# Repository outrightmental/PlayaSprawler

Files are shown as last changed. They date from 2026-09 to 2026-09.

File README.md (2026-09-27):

# Playa Sprawler

**Open-source personal mobility optimized for accessibility and maintainability.**
A camp chair on four identical, hot-swappable, self-powered wheel modules — packed into one piece
of Burner Express luggage, rated to the rider's mass down to every tube, joint and cord, and
repaired by a community fleet in under a minute.

Site: **https://playasprawler.outright.io** · structured after [BoardingFlow](https://boardingflow.outright.io/).

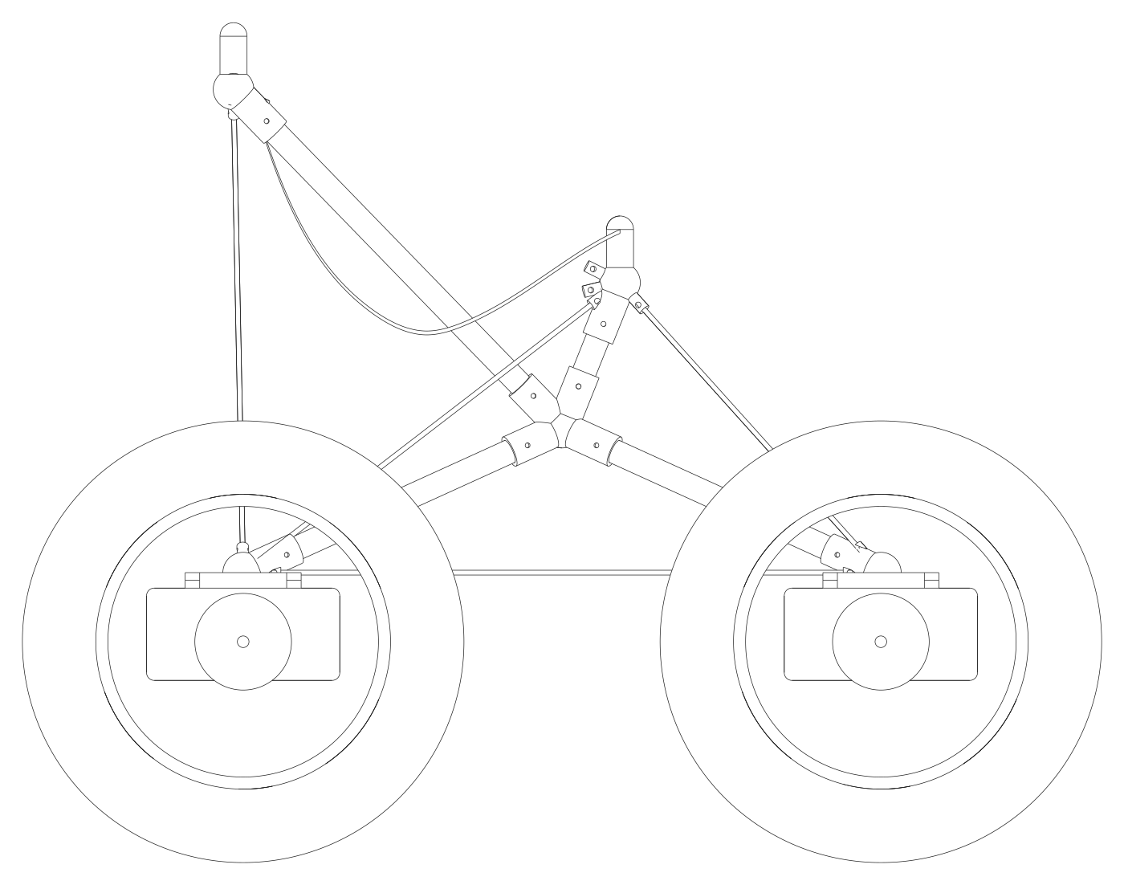
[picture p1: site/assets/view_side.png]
Side view, generated from the parameter file


## The idea in five lines

1. **Four identical wheel modules** (motor + gearbox + brake + battery + Ethernet node in one brick) dock anywhere on the frame; the dock tells the module which corner it is.
2. **Two identical control modules** (left tread, right tread) — lever, pedal, joystick, sip-puff: any input form publishes the same message.
3. **Ethernet only** for signals (M12 D-coded, UDP multicast pub/sub, no master); a separate SELV power bus. Traction current never crosses a dock.
4. **A rating code in the DNA**: every load-path part is analysed, proof-tested and marked PS-100 / PS-125 / PS-150; the vehicle's rating is the weakest part, enforced on the label and in firmware.
5. **One bag** — 62 linear inches, 50 lb — on the Burner Express bus. This constraint designed the vehicle.

## Repository

```
analysis/    ps_params.py (single source of truth) + truss, stability, energy, flotation, axle, packing → results/
cad/         CadQuery generator: joiners grown from the frame geometry, wheel-module carrier, assembly → exports/ (STEP, STL, SVG)
firmware/    PS-Bus reference simulator (deterministic + real UDP multicast) and message schemas
docs/        methodology, requirements, architecture, rating code, module specs, tests, fleet ops, regulatory, caveats, ADRs, sources
seat/        seat flat pattern (generated)
site/        the single-page site (src/ template + app.js → index.html via scripts/build_site.py)
scripts/     build_site.py, check_ratings.py (CI gate)
.github/     deploy.yml (main → S3 + CloudFront), pr.yml (analysis, CAD, simulator, site preview)
```

## Run it

```bash
pip install -r requirements.txt
cd analysis && python run_all.py            # results/results.md + results.json for all rating classes
cd ../cad && python ps_cad.py               # exports/*.step, *.stl, view_*.svg
python ../firmware/sim/psbus_sim.py --check # scripted hot-swap scenario with assertions
python ../scripts/check_ratings.py          # the rating gate CI runs
python ../scripts/build_site.py             # site/index.html
```

Change a number in `analysis/ps_params.py`; everything downstream regenerates. Never edit a
number in a doc or on the site by hand.

## Headline numbers (PS-125, from `analysis/results/results.md`)

| | |
|---|---|
| Bag | 660 × 450 × 450 mm (61.4 in), **22.49 kg of 22.68 kg** — margin 0.19 kg |
| Wheel module | 16 × 3.0 tubeless on a mini geared hub motor, 7s1p 85.7 Wh, 4.35 kg, 135 mm wide |
| Frame | 25 × 22 CF tube (0.74 kg), 10 printed joiners, 5 mm Dyneema cords, structural canvas seat |
| Worst safety factors, 2.5 g | tube 11.1 · cord 3.7 · seat edge 3.7 · axle 2.1 (assumed steel) |
| Stability | tip at 0.49 g lateral; limiter at 0.25 g; 2.0 m minimum radius at 8 km/h |
| Range | 23 km hard playa · 8 km soft playa · 2.5 km dry loose sand |
| Fail-safe | wheel stops 200 ms after the last valid command, 300 ms ramp |

## Read this first

`docs/13-caveats.md`. There is no prototype yet; the mass margin is 0.8 %; the axle steel is
assumed; the vehicle is only legal in Black Rock City as an Accessibility Vehicle for a rider with
a documented need.

## CI and deployment

Two workflows, mirroring the Outright Mental static-site pattern:

* **`pr.yml`** — on every pull request: analysis, rating gate, CAD export, simulator self-check,
  site build, and a `site-preview` artifact.
* **`deploy.yml`** — on push to `main`: the same build, then `aws s3 sync` to the
  `playasprawler.outright.io` bucket (immutable cache headers on `assets/`, `must-revalidate` on
  `index.html`) and a CloudFront invalidation.

One-time setup for the deploy target:

1. S3 bucket `playasprawler.outright.io` (private, served through CloudFront with an origin access control), default root object `index.html`.
2. CloudFront distribution with an ACM certificate for `playasprawler.outright.io` (us-east-1).
3. Route 53 / DNS: `playasprawler.outright.io` → the distribution.
4. Repository secrets: `AWS_ACCESS_KEY_ID`, `AWS_SECRET_ACCESS_KEY` (an IAM user limited to that bucket and `cloudfront:CreateInvalidation` on that distribution), `AWS_CLOUDFRONT_DISTRIBUTION_ID`.

## License

Hardware CERN-OHL-S-2.0 · software Apache-2.0 · documentation CC-BY-SA-4.0. See `LICENSE.md`.

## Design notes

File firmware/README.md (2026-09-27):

# Firmware

* `sim/psbus_sim.py` — the behavioural reference for every node type. `python sim/psbus_sim.py --check`
  runs the scripted hot-swap scenario on a deterministic in-process bus and asserts the timing rules;
  `--transport udp` runs a single node on real multicast for bench work.
* `schemas/psbus-message.schema.json` — JSON Schema for every PS-Bus v1 message.

Production targets (not yet written): an MCU with a hardware 100BASE-TX PHY per node, FOC motor
controller in the wheel module, zenoh-pico or a hand-rolled UDP loop. The simulator's node classes
are the spec those ports must match (`docs/06`).

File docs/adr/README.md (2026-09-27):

# Architecture decision records

* [ADR-001](ADR-001-per-module-battery.md) — The wheel module is the battery
* [ADR-002](ADR-002-skid-steer.md) — Skid steer, no steering mechanism
* [ADR-003](ADR-003-ethernet-m12-pubsub.md) — Ethernet-only signalling, UDP multicast, geographic addressing
* [ADR-004](ADR-004-16x3-tire.md) — 16 × 3.0 folding tubeless tire, packed deflated
* [ADR-005](ADR-005-cords-not-tubes.md) — Dyneema cords close the truss; the seat is structural
* [ADR-006](ADR-006-protocol-json-udp.md) — JSON over UDP multicast for v1, CBOR/zenoh reserved

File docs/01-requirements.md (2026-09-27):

# 01 — Requirements

Verification: **A** analysis · **T** test · **I** inspection · **D** demonstration. Numbers in
parentheses are the current design values from `analysis/results/results.md`.

## 1. Transport — one bag on the Burner Express

| ID | Requirement | V |
|---|---|---|
| REQ-010 | The complete vehicle, disassembled, fits in one soft bag ≤ 62 linear inches (chosen 660 × 450 × 450 mm = 61.4 in). | I |
| REQ-011 | Bag mass including the bag ≤ 50 lb / 22.68 kg (budget 22.49 kg, +0.19 kg margin). | T |
| REQ-012 | Packing and unpacking each take ≤ 15 min by one person without tools. | D |
| REQ-013 | Lithium cells travel inside the wheel modules; packs are ≤ 100 Wh each (85.7 Wh) and carry a state-of-charge indicator. | I |

## 2. Wheel module

| ID | Requirement | V |
|---|---|---|
| REQ-020 | All four wheel modules are identical and interchangeable in any dock without adjustment or configuration. | D |
| REQ-021 | A module can be exchanged in ≤ 60 s with the rider seated (one latch, no tools). | T |
| REQ-022 | Each module contains motor, gearbox, brake, controller, battery and network node; traction current never crosses the dock. | I |
| REQ-023 | Continuous drawbar per module ≥ 60 N at 8 km/h (soft playa 10 % grade needs 230 N total). | A/T |
| REQ-024 | Module mass ≤ 4.35 kg. | T |

## 3. Control module

| ID | Requirement | V |
|---|---|---|
| REQ-030 | Two control modules, one per side (CL, CR). Each publishes one normalised tread command `v ∈ [−1, +1]` at 50 Hz. | D |
| REQ-031 | Any input form (lever, pedal, joystick axis, sip-puff…) is a valid control module; the vehicle cannot tell them apart. | D |
| REQ-032 | A control module is hot-swappable; loss of one side stops that side within 200 ms + 300 ms ramp. | T |
| REQ-033 | Inputs have a mechanical or firmware dead-band ≥ 5 % around zero and return to zero when released. | T |

## 4. Network and power

| ID | Requirement | V |
|---|---|---|
| REQ-040 | Signals travel only over 100BASE-TX Ethernet on M12 D-coded connectors; no other signal wiring exists. | I |
| REQ-041 | Every node is a UDP-multicast pub/sub peer; there is no master for control messages. | D |
| REQ-042 | A node learns its role from the dock ID pin (geographic addressing); no per-node configuration. | D |
| REQ-043 | Primary power is a separate SELV bus (21–29.4 V) on M12 A-coded connectors, per-port limited to 5 A. | I/T |
| REQ-044 | Wheel nodes stop if no valid command arrives within 200 ms; all nodes stop on `veh/estop`. | T |
| REQ-045 | Losing the bus node (switch) is a safe state: all wheels stop. | T |

## 5. Structure and rating

| ID | Requirement | V |
|---|---|---|
| REQ-050 | Every vehicle carries a rating class PS-100 / PS-125 / PS-150 (payload kg). | I |
| REQ-051 | Every load-path part is rated and marked; vehicle rating = min(part ratings). | I |
| REQ-052 | Load cases LC1 (1.0 g static), LC2 (2.5 g vertical), LC3 (1.0 g + 0.6 g lateral), LC5 (0.5 W backrest) with SF tube 2.0, cord 3.0, fabric 3.0, print 1.5 on knocked-down allowables. | A |
| REQ-053 | Every load-path part passes a 1.5 × static proof load before marking. | T |
| REQ-054 | Static seated deflection at the rear tips ≤ 20 mm at class payload (15.5 mm at PS-125). | A/T |
| REQ-055 | No mechanism: the frame is kinematically stable in every load case with the seat installed. | A |
| REQ-056 | Printed parts use CF-filled nylon or PET with 100 % infill in load regions; datasheet strength knocked down by 0.5. | I |

## 6. Mobility and terrain

| ID | Requirement | V |
|---|---|---|
| REQ-060 | Speed cap 8 km/h (BRC 5 mph) in `run`; 2 km/h in `crawl`. | T |
| REQ-061 | Firmware turn-rate limiter `|ω|·|v| ≤ 0.25 g` (tip threshold 0.49 g). | A/T |
| REQ-062 | Range ≥ 15 km on hard playa at class payload (23 km predicted). | A/T |
| REQ-063 | Ground pressure ≤ 40 kPa at class payload for dry sand; 20 × 4.0 variant ≤ 30 kPa. | A/T |

## 7. Fleet

| ID | Requirement | V |
|---|---|---|
| REQ-070 | A fleet charger accepts any wheel module through the standard dock connector. | D |
| REQ-071 | Every part carries a QR label: class · part · batch · maker · proof date. | I |
| REQ-072 | The supervisor logs hello/rating records so a fleet steward can audit what was on which vehicle. | D |

## 8. Regulatory

| ID | Requirement | V |
|---|---|---|
| REQ-080 | The vehicle is designed and documented as a powered mobility device (ISO 7176 / EN 12184 reference); it is not a scooter or golf cart. | I |
| REQ-081 | Lights: white front, red rear, side marker at night per BRC vehicle policy. | I |
| REQ-082 | Riders check current BRC Accessibility Vehicle and GGNRA Ocean Beach rules before use (see `docs/12`). | I |

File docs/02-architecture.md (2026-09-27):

# 02 — Architecture

The sketch that started the project drew a box (battery · motor · gearbox · brake · electronics,
"4× redundant unit"), a camp-chair frame, two foot controls, a signal bus and a network
`W W W W — B — C C — I 1..n — L 1..n`. The architecture keeps exactly that shape.

```
            ┌────────────── PS-Bus (100BASE-TX, UDP multicast) ──────────────┐
            │                                                                 │
   W(FL) ───┤   W(FR) ───┤   W(RL) ───┤   W(RR) ───┤   C(CL) ──┤  C(CR) ──┤   I 1..n  L 1..n
     │            │           │            │            │           │          │       │
   ══╪════════════╪═══════════╪════════════╪════════════╪═══════════╪══════════╪═══════╪══  power bus (SELV 21–29.4 V)
                                        ┌───┴───┐
                                        │   B   │  unmanaged switch + supervisor + charge input
                                        └───────┘
```

## Node types

| Node | Count | Role | Publishes | Subscribes |
|---|---|---|---|---|
| **W** wheel module | 4 | traction, braking, battery, node | `wheel/<pos>/status` 10 Hz, `node/<serial>/hello` 1 Hz | `ctrl/tread/<side>`, `veh/mode`, `veh/estop` |
| **C** control module | 2 | rider input → normalised tread command | `ctrl/tread/<side>` 50 Hz, hello | `veh/mode` (for haptics/LED) |
| **B** bus node | 1 | 8-port unmanaged switch, supervisor MCU, power distribution, charge input, e-stop button | `veh/mode`, `veh/estop`, `veh/log` | everything |
| **I** input | 0..n | horn, lights switch, phone app, spare inputs | `input/<n>/event` | — |
| **L** load | 0..n | lights, sound, whatever the seat decorator wants | — | `light/<n>/cmd`, `veh/mode` |

Every port on the vehicle is the same port: **DATA** (M12 D-coded, Ethernet) + **POWER/ID**
(M12 A-coded, 4 pins: bus +, bus −, ID, spare). The ID pin is a resistor to bus − inside the dock;
its value tells the node which dock it is in: FL, FR, RL, RR, CL, CR, AUX1..n.

## Skid steer

There is no steering mechanism. The left tread command drives both left wheels, the right tread
command both right wheels. Turning = differential speed. This is what makes the four modules
identical: no module knows anything about steering geometry, only which side it is on
(and left-side nodes invert their motor sign).

## Power

Each wheel module carries a 7s1p pack (25.2 V nominal). The vehicle power bus runs at pack
voltage. Each module connects to the bus through an ideal-diode discharge path (so the highest
pack feeds the bus, never back-feeds another pack) and a current-limited charge path (≤ 3–5 A).
Consequences:

* one charger on the B node charges and balances all four packs;
* control modules, lights and the switch buck-convert from the bus; no PoE hardware needed;
* traction current stays inside the module — the dock connector only carries ≤ 5 A.

## Safety chain (what stops the wheels)

1. Rider releases input → command goes to 0 → wheels ramp down at 0.30 g.
2. Any control message stops arriving → wheel stops itself within 200 ms + 300 ms ramp.
3. Supervisor sees a missing wheel (status silent > 250 ms) → `veh/mode = stop`.
4. Any part reports a rating below the rider class → `veh/mode = crawl` (2 km/h).
5. E-stop button on B, or any node publishing `veh/estop` → all stop.
6. B node dies → no switch → no messages → every wheel stops by rule 2.

## Structure

The frame is a tensegrity-flavoured camp chair: two printed hubs joined by the seat rail, four
carbon legs down to the four docks, two carbon poles up to the backrest tips, two short posts to
the front seat tips, and Dyneema cords (side, rear, X-braces, forestays, aftstays, crossed
backstays) that close the truss. The canvas seat is a structural member: its side straps and edge
webbing carry real load, which is why it is rated like everything else (`docs/08`).

## Where things live

```
analysis/   parameters + all calculations → results/
cad/        CadQuery generator → exports/ (STEP, STL, SVG)
firmware/   PS-Bus reference simulator + message schemas
docs/       this folder, ADRs, sources
seat/       seat pattern
site/       playasprawler.outright.io
```

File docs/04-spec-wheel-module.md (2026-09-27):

# 04 — Wheel module spec (interface v1)

**One part number. Four per vehicle. Any dock.**

## Interface (frozen)

| Item | Spec |
|---|---|
| Mechanical | fore/aft-symmetric T-rail on top of the carrier (stem 12 × 8 mm, head 24 × 8 mm, 120 mm long) sliding into the dock shoe; one Ø8 mm spring drop-pin captures it. Rail top = dock plane 300 mm above ground. |
| Load path | rail → shoe → printed dock joiner → legs/cords. Rated per class like every other load-path part. |
| Data | M12 D-coded female, 100BASE-TX. |
| Power/ID | M12 A-coded 4-pin female: 1 bus +, 2 bus −, 3 ID (reads dock resistor), 4 spare. Port fuse 5 A. |
| Module envelope | 135 mm wide (45 carrier + 5 gap + 76 tire + 9 nut), 457 mm OD inflated, 400 mm deflated. |
| Mass | ≤ 4.35 kg. |
| Ingress | IP54 module, IP65 connectors, mated or capped. |

## Internals (free to improve within the envelope)

| Sub-part | Baseline |
|---|---|
| Wheel | 16 × 3.0 (ISO 76-305) folding-bead tubeless tire on a 20-hole rim laced to the hub motor; sealant. |
| Motor | mini geared hub motor, 250 W nominal / 500 W peak, 20 N·m rated / 35 N·m peak, no-clutch (regen-capable) variant preferred so regen braking and hold-on-slope work. |
| Brake | regen + the gearbox's holding torque for service; a friction parking brake is not required at 8 km/h (T-8 verifies the 1.5 m stop on 10 % grade). |
| Battery | 7s1p 18650 3.4 Ah (25.2 V, 85.7 Wh, 0.41 kg) with BMS, on the inboard carrier. Fuel gauge LED. |
| Controller | FOC controller with hall + current sensing; speed control with torque limit; limits from `veh/mode`. |
| Node | small MCU with 100BASE-TX PHY (or an ESP32-class MCU + external PHY); runs the PS-Bus reference behaviour. |
| Carrier | printed "brick" 45 mm thick inboard of the wheel; aluminium torque plates clamp the axle flats; single-sided axle clamp (see caveat). |

## Behaviour

* On power-up: read ID pin → role (FL/FR/RL/RR) → side (left inverts motor sign) → subscribe.
* `ctrl/tread/<side>` at 50 Hz: `v ∈ [−1, 1]` → target speed `v × cap(mode)`; accel ≤ 0.25 g, decel ≤ 0.30 g.
* No valid command for 200 ms → ramp to zero in 300 ms and hold.
* Publish `wheel/<pos>/status` at 10 Hz (speed, SoC, temperature, fault, stop reason) and `hello` at 1 Hz (serial, rating, firmware).
* Thermal derate above 80 °C winding; cut at 95 °C.

## Analysis summary (PS-125)

| Quantity | Value |
|---|---|
| Per-wheel torque, hard playa flat / soft 10 % | 1.6 / 13.2 N·m |
| Per-wheel torque, dry loose sand 10 % | 24.7 N·m → above rated: derate speed |
| Axle bending + torque, LC2 | 368 MPa von Mises, SF 2.1 on assumed 785 MPa yield |
| Ground pressure 16 × 3.0 at 40 kPa | 90 cm² patch, 16 mm deflection — OK |

## Variants

* **PS-Lite**: 16 × 2.4 tire, −0.2 kg per module (mass margin ~5 %), poorer sand flotation.
* **PS-Sand**: 20 × 4.0 tire, 30 kPa at 30 psi-equivalent; does not fit the one-bag pack (two bags, both allowed on one ticket).

## Charging

The fleet charger is a dock: same rail, same two M12 connectors. Any module docks to charge. The
charger publishes `charger/<slot>/status` on the fleet LAN so stewards see the shelf.

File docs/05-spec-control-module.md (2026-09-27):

# 05 — Control module spec (interface v1)

**Two per vehicle: CL and CR. Any input form. Same message.**

## Interface (frozen)

| Item | Spec |
|---|---|
| Mechanical | 25 mm tube clamp onto the front control rail (CTRL_RAIL) or the seat rail; one lever bolt. Position is adjustable along the rail. |
| Data / Power-ID | the same M12 D-coded + M12 A-coded pair as every port. The dock ID says CL or CR. |
| Message | `ctrl/tread/<side>` at 50 Hz: `{ "v": -1.0..1.0, "seq": n, "src": serial, "input": "lever|pedal|..." }` |
| Zero | mechanical return-to-centre; firmware dead-band ≥ 5 %. |
| Mass | ≤ 0.30 kg. |

## Input forms (all valid)

| Form | Who | Notes |
|---|---|---|
| Hand lever (fore/aft) | most riders | spring-centred, 30° travel |
| Foot pedal (rocker) | riders without the use of one hand | heel-toe rocker, 20° travel |
| Joystick half (one axis) | one-handed riders using two stacked modules | two modules on one rail clamp |
| Sip-puff / switch pairs | as needed | publishes ±0.6 steps with ramping |

The sketch's example — a rider missing the left leg and the right arm — uses a **left lever** and a
**right pedal**. The wheels cannot tell. The simulator (`firmware/sim/psbus_sim.py`) runs exactly
this configuration.

## Behaviour

* Publish at 50 Hz regardless of change (the wheels use the stream as a heartbeat).
* `seq` increments; wheels ignore out-of-order messages.
* If the module's own sensor faults, it publishes `v = 0` with `"fault": true` rather than going silent, so the vehicle stops smoothly instead of by timeout.
* Optional haptic/LED shows `veh/mode` (run / crawl / stop).

## Turn-rate limiter (lives in the wheels, fed by both controls)

Each wheel knows both sides' commands (both are on the bus). Before applying its own target it
scales both symmetrically so that `|ω|·|v| ≤ 0.25 g` with `ω = (vR − vL)/track`. Result at 8 km/h:
minimum radius 2.0 m; at 1 m radius the cap is 5.6 km/h.

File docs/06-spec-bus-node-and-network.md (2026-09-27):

# 06 — Bus node and network spec (PS-Bus v1)

## Physical layer

* **Data**: 100BASE-TX over M12 D-coded connectors and cables (IP67). Star topology through the
  8-port unmanaged switch in the B node. Cable lengths ≤ 2 m.
* **Power/ID**: separate M12 A-coded 4-pin: bus +, bus −, ID, spare. SELV 21–29.4 V. Per-port eFuse
  5 A on the B node. ID pin: resistor ladder inside each dock/port.

| ID resistor | Role |
|---|---|
| 1.0 kΩ | FL |
| 2.2 kΩ | FR |
| 4.7 kΩ | RL |
| 10 kΩ | RR |
| 22 kΩ | CL |
| 47 kΩ | CR |
| 100 kΩ | AUX (lights, inputs) |
| open | charger dock |

"Do better than Ethernet": the interface reserves **10BASE-T1S (single-pair Ethernet, multidrop)**
as PS-Bus v2 — one twisted pair, no switch, same IP stack. Until it is proven on the playa, v1 is
plain 100BASE-TX because every MCU, laptop and phone can speak it.

## Transport

UDP multicast `239.77.83.1:7783`, one JSON object per datagram (CBOR reserved for v2). No broker,
no master. The B node's switch just forwards frames. Schema: `firmware/schemas/psbus-message.schema.json`.

Envelope: `{ "t": "<topic>", "ts": <seconds, node clock>, ...payload }`

## Topics

| Topic | Rate | Payload | Publisher |
|---|---|---|---|
| `ctrl/tread/left` · `ctrl/tread/right` | 50 Hz | `v`, `seq`, `src`, `input` | control modules |
| `wheel/<FL|FR|RL|RR>/status` | 10 Hz | `serial`, `v_kmh`, `soc`, `temp_c`, `fault`, `stop` | wheel modules |
| `node/<serial>/hello` | 1 Hz | `kind`, `dock`, `rating`, `fw` | every node |
| `veh/mode` | 10 Hz | `mode` (run/crawl/stop), `rating`, `rider_class` | supervisor |
| `veh/estop` | 10 Hz | `active` | supervisor, any node |
| `light/<n>/cmd` | on change | `on`, `pattern` | anyone |
| `input/<n>/event` | on change | `event` | inputs |
| `veh/log` | on event | text | supervisor |

## Rules

1. **Heartbeat by stream.** Wheels stop 200 ms after the last valid tread command and ramp to zero in 300 ms.
2. **One node per dock.** A `hello` from a new serial on an occupied dock supersedes the old occupant immediately (this is how a hot-swap is recognised without link-state).
3. **Presence = status stream.** The supervisor treats a wheel as present only while its status is < 250 ms old (2.5 frames).
4. **Rating.** `vehicle_rating = min(rating of live nodes ∪ frame rating)`; `crawl` if below rider class.
5. **Malformed = absent.** Bad JSON, out-of-range `v`, stale `seq` are dropped; the timeout does the rest.
6. **Modes.** `run` cap 8 km/h · `crawl` cap 2 km/h · `stop` cap 0.

## B node hardware

8-port 100 Mb unmanaged switch board, supervisor MCU, 6 × (M12 D + M12 A) ports, e-stop mushroom,
charge input (XT60 → bus through a CC/CV limiter), optional extra pack bay. Mass budget 0.55 kg.
If it dies the vehicle stops (rule 1) — it is a swappable unit like everything else.

## Reference implementation

`firmware/sim/psbus_sim.py` is the behavioural reference: the same node classes run against a
deterministic in-process bus (CI) or real UDP multicast (bench). Candidate production stack:
zenoh-pico or a hand-rolled UDP loop on an MCU with a hardware PHY.

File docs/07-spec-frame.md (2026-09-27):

# 07 — Frame spec

Coordinates: x forward, y left, z up, mm, ground z = 0. All from `analysis/ps_params.py`;
generated geometry table in `cad/exports/geometry.md`.

## Nodes

| Node | x | y | z | Joiner |
|---|---|---|---|---|
| HUB_L/R | 0 | ±180 | 450 | printed hub: seat rail, 2 legs, pole, post, 2 X-cord eyes |
| DOCK_FL/FR | +330 | ±280 | 300 | printed dock: leg socket, control rail socket, side/X/forestay eyes, T-slot shoe + pin |
| DOCK_RL/RR | −330 | ±280 | 300 | printed dock: leg socket, rear cord, side/X/aftstay/backstay eyes, shoe + pin |
| FTIP_L/R | +60 | ±180 | 600 | printed front tip: post socket, seat pocket peg, forestay/aftstay eyes |
| RTIP_L/R | −340 | ±230 | 800 | printed rear tip: pole socket, top rail socket, seat pocket peg, backstay eye |

Track 691 mm · wheelbase 660 mm · seat pan ≈ 530 mm · backrest top 800 mm.

## Members

| Member | Kind | Length | Packed |
|---|---|---|---|
| SEAT_RAIL (HUB_L–HUB_R) | 25 × 22 CF tube | 360 | 1 × 360 |
| CTRL_RAIL (DOCK_FL–FR) | tube | 560 | 2 × 280 shock-corded |
| TOP_RAIL (RTIP_L–R) | tube | 460 | 2 × 230 |
| LEG_F/R × 4 (hub–dock) | tube | 376 | 1 × 376 |
| POLE × 2 (hub–rear tip) | tube | 491 | 2 × 245 |
| POST × 2 (hub–front tip) | tube | 162 | 1 |
| SIDE_CORD × 2, REAR_CORD, XF × 2, XR × 2 | 5 mm Dyneema | — | coiled |
| FORESTAY × 2 (FTIP–front dock), AFTSTAY × 2 (FTIP–rear dock, outboard of the seat), BACKSTAY × 2 (RTIP–opposite rear dock, crossed) | 5 mm Dyneema | — | coiled |
| SIDE_STRAP × 2, SLING, SEAT_CROSS, SEAT_FRONT_EDGE | seat canvas / webbing | — | rolled |

## Why this shape

* The camp-chair backrest is a mechanism unless the seat is structural: the straight side straps
  (FTIP→RTIP) and the crossed backstays are what make LC3 and LC5 stable. Remove the seat and the
  backrest folds — by design, that is how it packs.
* Forestays run straight to the same-side front dock so nothing crosses the rider's leg space.
* Tubes are 25 × 22 roll-wrapped CF for every member — one tube spec, one socket, one cutting list.
  Buckling SF ≥ 9 at 2.5 g in every class; the size is set by joint bearing and stiffness.

## Joiners

Generated by `cad/ps_cad.py` from the node geometry: a 21 mm core, one socket boss per tube
(33 mm OD, 50 mm deep, 4 mm wall, M5 cross pin), one anchor rod with a Ø6 mm cross hole per cord,
a T-slot shoe under each dock, a Ø28 × 55 mm domed peg on each seat tip. Print PA12-CF / PET-CF,
100 % infill, sockets oriented along the print axis where possible. Every joiner is proof-tested
(T-2, T-5) before it is marked.

## Results (PS-125, from `analysis/results/results.md`)

| Case | Max deflection | Worst tube SF | Worst cord SF | Worst seat-edge SF |
|---|---|---|---|---|
| LC1 static | 15.5 mm | 27.7 | 9.4 | 9.1 |
| LC2 2.5 g | 38.8 mm | 11.1 | 3.7 | 3.7 |
| LC3 lateral | 53.0 mm | 12.6 | 4.8 | 5.7 |
| LC5 backrest | 33.2 mm | 18.3 | 6.6 | 7.0 |

Peak member forces at LC2: legs −3.9 kN (compression), side cords +2.4 kN, rear sling +1.6 kN.

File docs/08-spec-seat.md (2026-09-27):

# 08 — Seat spec (the personal part)

The seat is one piece of canvas with **four corner pockets** that slip over the domed pegs on the
two front tips and two rear tips — exactly like the REI camp chair the sketch came from. It is the
only part that is never swapped, so it is the part people decorate. It is also structural.

## Structure

| Element | Spec | Rating role |
|---|---|---|
| Body | 1000D Cordura or 600D polyester, UV-stable; 2 layers in the sling | carries the rider (SLING_F/R, SEAT_CROSS) |
| Side straps | 25 mm tubular nylon webbing sewn full length FTIP→RTIP both sides, bar-tacked at the pockets | SIDE_STRAP (fabric member, 479 N at LC2) |
| Front edge | webbing FTIP→FTIP | SEAT_FRONT_EDGE |
| Corner pockets | double-layer cups, Ø32 mm × 70 mm deep, webbing loop through each | transfer 1.6 kN (rear, LC2) into the pegs |
| Edge strength | ≥ 6 kN pull test on the finished edge (T-4) | SF 3.0 at PS-150 |

The pattern is in `seat/seat-pattern.svg` (flat, with seam allowances). Sew with bonded nylon #92
or #138. Every finished seat is proof-loaded (T-5) and labelled with its class like a joiner.

## Decoration rules (so the art never compromises the rating)

1. Paint, dye, patches, LEDs: anything on the **face** of the body panel is free.
2. Do not cut, burn or sew through the side straps, the front-edge webbing or the pockets.
3. Added mass on the seat counts toward the payload, not the vehicle; keep lights on the L bus with
   an M12 AUX port rather than a separate battery.
4. Dust cover: the seat comes off in 20 s — take it inside at night.

## Geometry

Chord FTIP→RTIP 447 mm at 27° rake; sag ratio 0.33 (150 mm) sets the sling angle and therefore
the horizontal pull on the tips; front share of seated weight 0.45. Changing the sag changes the
loads — re-run `analysis/run_all.py` after any pattern change (`SEAT_SAG_MM`).

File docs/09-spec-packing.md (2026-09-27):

# 09 — Packing spec (one bag, 50 lb)

**Constraint** (Burner Express, verified 2026-09): 62 linear inches and 50 lb per luggage item;
two items plus a small carry-on per ticket. E-bike batteries are accepted inside the luggage.

## Bag

660 × 450 × 450 mm soft duffel (61.4 in), padded ends, internal 640 × 430 × 430 mm.

## Layout

```
 ┌──────────────────────────────────── 640 ────────────────────────────────────┐
 │ W │ W │ W │ W │  tubes (≤376 mm, shock-corded), cords, seat, B node, controls │
 │135│135│135│135│                          100 mm slab                         │
 └────────────────────────────────────────────────────────────────────────────┘
   four wheel modules stacked axially, TIRES DEFLATED (Ø400 mm) — inflated Ø457 does not fit
   corner voids beside the stack (~32 L) take the two control modules, harness and pump
```

* Tires deflated to pack: tubeless with sealant reseats with a mini pump on site (T-11 times it).
* Longest tube segment 376 mm (legs); rails and poles split with internal shock cord.
* Seat rolled around the cords; B node in its own padded pouch.

## Mass budget (target, kg)

| Item | kg |
|---|---|
| Wheel modules × 4 | 17.40 |
| Frame tubes | 0.74 |
| Joiners + hardware | 0.90 |
| Cords + tensioners | 0.15 |
| Seat | 0.70 |
| Control modules × 2 | 0.60 |
| Bus node | 0.55 |
| Harness | 0.65 |
| Bag | 0.80 |
| **Total** | **22.49** of 22.68 (50 lb) — **+0.19 kg, +0.8 %** |

This is the binding constraint of the whole design and the margin is thin. Mitigations, in order:

1. Weigh every prototype part; the budget is a target, not a measurement.
2. PS-Lite wheels (16 × 2.4) recover ~0.8 kg.
3. Two-bag pack (allowed on one ticket): modules in one bag, everything else in the other. PS-Sand (20 × 4.0) needs this anyway.
4. Carry the B node and controls in the carry-on (9 × 10 × 17 in).

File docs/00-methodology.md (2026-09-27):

# 00 — Methodology

Playa Sprawler is run as an engineering project, not a maker sketch. The method is a small V-model
with one hard rule: **no number appears in a spec, a drawing or the website unless a script in
`analysis/` produced it from `analysis/ps_params.py`.**

## The V

| Left side (definition) | Right side (proof) |
|---|---|
| **Requirements** `docs/01` — numbered `REQ-xxx`, each with a verification method (A = analysis, T = test, I = inspection, D = demonstration). | **Acceptance** — every `REQ` is closed by the named method and logged in the rating record. |
| **Architecture** `docs/02` — modules and the interfaces between them (dock, PS-Bus, power bus, seat pockets). | **Integration tests** `docs/10 §T-9..T-11` — hot-swap timing, comms fail-safe, packing. |
| **Module specs** `docs/04..08` — one file per swappable unit; interface first, internals second. | **Module tests** `docs/10 §T-1..T-8` — bend, socket, latch, cord, proof load, drop, brake, dust. |
| **Analysis** `analysis/*.py` — truss, stability, energy, flotation, axle, packing. | **Test correlation** — measured vs predicted; the parameter file is corrected, never the spec. |

## Rules of the project

1. **Single source of truth.** `analysis/ps_params.py` holds every design parameter. CAD (`cad/ps_cad.py`),
   analysis, the docs tables and the site read from it or from `analysis/results/results.json`.
2. **Ratings are computed, then proven.** A part's class (PS-100/125/150, `docs/03`) is first set by
   analysis with the stated knock-downs and safety factors, then confirmed by a proof test on *every*
   load-path part before the part is marked. Analysis alone never rates a part.
3. **Vehicle rating = min(part ratings).** Enforced twice: on the label (QR) and in firmware
   (`veh/mode` drops to `crawl` if any live node reports a rating below the rider class).
4. **Interfaces are frozen before internals.** The dock (rail + pin + two M12 connectors), the PS-Bus
   message set and the seat-pocket geometry are versioned interfaces (`v1`). Anyone may redesign the
   inside of a wheel module; nobody may change the dock without a new interface version.
5. **Decisions are recorded** as ADRs in `docs/adr/` with the alternatives that lost.
6. **Caveats are first-class.** `docs/13` lists what is idealised, unverified or marginal. The site
   repeats them; hiding them would defeat the point of a safety code.
7. **Traceability.** Requirement → analysis script → result → test → rating record. The table below is
   the index.

## Traceability index

| REQ | Where analysed | Where tested |
|---|---|---|
| REQ-010..013 (one bag) | `analysis/packing.py` | T-11 |
| REQ-020..024 (wheel module) | `energy.py`, `flotation.py`, `axle.py` | T-6, T-7, T-8, T-10 |
| REQ-030..033 (controls) | `firmware/sim/psbus_sim.py` | T-9, T-10 |
| REQ-040..045 (network + power) | `psbus_sim.py` | T-9 |
| REQ-050..056 (structure + rating) | `frame_truss.py` | T-1..T-5 |
| REQ-060..063 (mobility + terrain) | `stability.py`, `energy.py`, `flotation.py` | T-7, field trials |
| REQ-070..072 (fleet) | `docs/11` | fleet drills |
| REQ-080..082 (regulatory) | `docs/12` | inspection |

## Toolchain

* Python 3.12 + numpy for analysis; CadQuery 2.8 for parametric CAD (STEP/STL/SVG exports).
* Everything runs in CI on every pull request (`.github/workflows/pr.yml`): analysis, CAD export,
  simulator self-checks, site build. A red build blocks the merge — the same way a failed proof test
  blocks a part.

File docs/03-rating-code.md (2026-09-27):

# 03 — Rating code (the safety DNA)

## Classes

| Class | Payload (rider + carried gear) | Typical use |
|---|---|---|
| PS-100 | 100 kg | lighter riders, PS-Lite wheels |
| PS-125 | 125 kg | **default** fleet build |
| PS-150 | 150 kg | heavier riders; seat-edge SF sits exactly at the 3.0 target |

A **rider class** is chosen at sign-out (rider mass + gear, rounded up). The **vehicle rating** is
the minimum class marked on any load-path part installed. Rider class ≤ vehicle rating, or the
vehicle runs in `crawl`.

## Load cases (multiples of payload weight W)

| Case | Vertical | Lateral | Backrest | Kind |
|---|---|---|---|---|
| LC1 static seated | 1.0 W | — | — | deflection check |
| LC2 dynamic vertical (bump / 150 mm drop) | 2.5 W | — | — | ultimate |
| LC3 lateral skid / turn | 1.0 W | 0.6 W | — | ultimate |
| LC5 backrest lean | 1.0 W | — | 0.5 W | ultimate |

## Allowables and safety factors

| Material | Allowable basis | Knock-down | SF |
|---|---|---|---|
| Roll-wrapped CF tube 25 × 22 | 450 MPa ultimate; Euler buckling with E = 80 GPa | — | 2.0 |
| Dyneema SK78 5 mm | MBL 18 kN | 0.5 for knots (spliced eyes preferred) | 3.0 |
| Seat fabric edge (1000D + 25 mm webbing) | 6 kN pull test | — | 3.0 |
| Printed joiner (PA12-CF / PET-CF, 100 % infill) | 80 MPa datasheet | 0.5 | 1.5 |
| Hub-motor axle (12 mm, flats) | 785 MPa yield **assumed** | verify per motor | 1.5 |

Knock-downs are applied first, then SF. Printed parts get the harshest treatment on purpose:
anisotropy, moisture, printer variance and UV are all real on the playa.

## Proof test

Before a part is marked, it is loaded to **1.5 × the LC1 load of its class** for 60 s with no
visible damage and no permanent set > 0.5 mm (`docs/10 T-5`). Proof-tested parts get a QR label:

```
PS-125 · JOINER-HUB-L · batch 2026-09-A · maker <id> · proof 2026-09-14
```

## What is a load-path part

Tubes, joiners, cords, seat canvas, wheel-module carrier, axle clamp, dock pins, control-module
mounts. Batteries, boards and lights are not — but they carry the same label format for fleet logs.

## Firmware enforcement

Every node's `hello` carries its rating. The supervisor computes
`vehicle_rating = min(rating of every live node)` and publishes it in `veh/mode`.
If `vehicle_rating < rider_class`, mode is `crawl` (2 km/h). This catches the case the label cannot:
someone swapping a PS-100 wheel module onto a PS-150 rider's vehicle in the dark. The frame's
rating (which has no node) is entered once on the B node at assembly and included in the min.

## Current margins (from `analysis/results/results.md`)

| Class | Worst tube SF (buckling) | Worst cord SF | Worst seat-edge SF | Axle SF (assumed steel) | Status |
|---|---|---|---|---|---|
| PS-100 | 13.9 | 4.7 | 4.6 | 2.4 | passes |
| PS-125 | 11.1 | 3.7 | 3.7 | 2.1 | passes |
| PS-150 | 9.2 | 3.1 | 3.0 | 1.9 | passes at the target |

Tubes are deliberately oversize (their size is set by joint bearing and stiffness, not by strength);
cords and the seat edge are the governing parts.

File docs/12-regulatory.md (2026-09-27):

# 12 — Regulatory framing

**This is a powered mobility device, not a scooter.** That is a design decision with consequences,
not a label.

## Black Rock City

* City speed limit 5 mph → firmware cap 8 km/h.
* Seated electric scooters, e-motorcycles and golf carts are disallowed personal transport.
* Four-wheeled seated electric vehicles are permitted only as **Accessibility Vehicles** (electric
  wheelchairs and 3–4-wheel mobility scooters) for people with documented mobility needs, with the
  DMV process that goes with it; otherwise a vehicle needs a Mutant Vehicle licence.
* Lights at night: white front, red rear, sides visible.

Design consequences: seat height and controls follow the mobility-device pattern; speed and
turn-rate limits are firmware-enforced, not optional; the documentation set references ISO 7176
(wheelchairs) and EN 12184 (electrically powered wheelchairs) test families so a rider can show an
inspector what the vehicle is.

## Ocean Beach, San Francisco (GGNRA / National Park Service)

Motor vehicles are prohibited on the beach. Wheelchairs and other power-driven mobility devices
(OPDMDs) used by people with mobility disabilities are the ADA exception, subject to the park's
current assessment. Riders must check current GGNRA policy before use; the project does not claim
a right of access.

## Batteries in transit

Burner Express accepts e-bikes and their batteries in luggage. Packs here are ≤ 100 Wh each (the
airline threshold used as a conservative design limit), with SoC indicators and terminal caps.

## What the project does not do

It does not certify anything. Rating labels are a community practice, not a legal mark. See
`docs/13`.

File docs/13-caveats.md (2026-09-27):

# 13 — Caveats (read before building)

1. **The 50 lb margin is 0.19 kg (0.8 %).** The mass budget is a target. Real parts will be weighed;
   expect to need PS-Lite wheels or the two-bag pack on the first prototypes.
2. **Axle steel is assumed.** SF 2.1 at PS-125 assumes a 785 MPa yield 40Cr axle. Verify per motor
   model; if unverifiable, the carrier must support the axle on both sides (costs ~60 g and 20 mm of width).
3. **The truss model is idealised**: pin joints, tension-only cords, seat modelled as five straight
   fabric members, no joint compliance. Deflections are lower bounds; forces are reasonable; joint
   bearing is checked separately and conservatively.
4. **Printed-part allowables** use a 0.5 knock-down on datasheet strength. That is an engineering
   guess until T-2/T-5 data exist for the chosen filament and printer.
5. **Range figures** assume drive efficiency 0.70 at low speed and textbook rolling-resistance
   coefficients (hard playa 0.02, soft 0.06, wet sand 0.05, dry loose sand 0.20). Dry sand range
   (2.5 km) is a warning, not a feature.
6. **Deflated-tire packing** is the only way the 16 × 3.0 wheel fits the section. Tubeless
   reseating on the playa with a mini pump must be proven (T-11).
7. **Regulatory**: the vehicle is only legal in BRC as an Accessibility Vehicle for riders with a
   documented need; on Ocean Beach only as an OPDMD under ADA. Nothing here is a permit.
8. **Hot-swap while rolling** is a demonstrated protocol behaviour, not an invitation; the procedure
   says stop first.
9. **Single supplier risk**: the mini geared hub motor class is commodity, but axle flats, wire
   exits and gear ratios vary by vendor. The carrier is parametric for that reason.
10. **No prototype exists yet.** Everything here is analysis, CAD and simulation. Stage 0 of the
    rollout is a single wheel module on a test rig.

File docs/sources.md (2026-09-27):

# Sources

Verified 2026-09-08. Numbered as cited on the site.

1. Burner Express Bus — luggage limits (62 linear inches, 50 lb per item; two items + carry-on 9 × 10 × 17 in): https://help.burningman.org/hc/en-us/articles/360024792811-BXBus-Is-there-a-limit-on-the-amount-of-gear-I-can-bring
2. Burner Express Bus information and terms (routes, e-bikes in cases): https://burnerexpress.burningman.org/burner-express-bus-information/ and https://burnerexpress.burningman.org/burner-express-bus-terms-and-conditions/
3. Burning Man Journal, July 2026 — disallowed scooters, e-motorcycles and similar vehicles in BRC: https://journal.burningman.org/2026/07/black-rock-city/survive-and-thrive/disallowed-vehicles-in-brc-2026/
4. Burning Man — Accessibility Vehicles (electric wheelchairs, 3–4-wheel mobility scooters, DMV process): https://burningman.org/black-rock-city/bring-your-mutant-vehicle/accessibility-vehicles/ and https://help.burningman.org/hc/en-us/articles/360024793811-What-is-an-Accessibility-Vehicle
5. Burning Man Survival Guide — getting around BRC, mutant vehicles and the DMV (5 mph): https://survival.burningman.org/getting-around-brc/mutant-vehicles-the-dmv/
6. ISO 7176 (wheelchairs) and EN 12184 (electrically powered wheelchairs, scooters and their chargers) — test families referenced for the mobility-device framing.
7. ADA — other power-driven mobility devices (28 CFR 35.137 / 36.311) — basis for beach access as a mobility device; GGNRA policy to be checked at time of use.
8. BoardingFlow (template for this project's structure): https://boardingflow.outright.io/
9. Rolling-resistance coefficients and tire-flotation rules of thumb: standard vehicle-dynamics references (e.g. Wong, *Theory of Ground Vehicles*) — treated as assumptions, see `docs/13`.
10. Dyneema SK78 5 mm single braid MBL ≈ 18 kN — manufacturer datasheets; knot knock-down 0.5 per rigging practice.

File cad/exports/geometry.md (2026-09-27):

| Node | x | y | z |
|---|---|---|---|
| HUB_L | 0 | 180 | 450 |
| DOCK_FL | 330 | 280 | 300 |
| DOCK_RL | -330 | 280 | 300 |
| FTIP_L | 60 | 180 | 600 |
| RTIP_L | -340 | 230 | 800 |
| SEAT_L | -140 | 205 | 550 |
| HUB_R | 0 | -180 | 450 |
| DOCK_FR | 330 | -280 | 300 |
| DOCK_RR | -330 | -280 | 300 |
| FTIP_R | 60 | -180 | 600 |
| RTIP_R | -340 | -230 | 800 |
| SEAT_R | -140 | -205 | 550 |

| Member | From | To | Kind | Length (mm) |
|---|---|---|---|---|
| SEAT_RAIL | HUB_L | HUB_R | tube | 360 |
| CTRL_RAIL | DOCK_FL | DOCK_FR | tube | 560 |
| TOP_RAIL | RTIP_L | RTIP_R | tube | 460 |
| SEAT_CROSS | SEAT_L | SEAT_R | fabric | 410 |
| SEAT_FRONT_EDGE | FTIP_L | FTIP_R | fabric | 360 |
| REAR_CORD | DOCK_RL | DOCK_RR | cord | 560 |
| XF_1 | DOCK_FL | HUB_R | cord | 586 |
| XF_2 | DOCK_FR | HUB_L | cord | 586 |
| XR_1 | DOCK_RL | HUB_R | cord | 586 |
| XR_2 | DOCK_RR | HUB_L | cord | 586 |
| LEG_FL | HUB_L | DOCK_FL | tube | 376 |
| LEG_RL | HUB_L | DOCK_RL | tube | 376 |
| POLE_L | HUB_L | RTIP_L | tube | 491 |
| POST_L | HUB_L | FTIP_L | tube | 162 |
| SIDE_CORD_L | DOCK_FL | DOCK_RL | cord | 660 |
| FORESTAY_L | FTIP_L | DOCK_FL | cord | 416 |
| AFTSTAY_L | FTIP_L | DOCK_RL | cord | 502 |
| BACKSTAY_L | RTIP_L | DOCK_RR | cord | 714 |
| SIDE_STRAP_L | FTIP_L | RTIP_L | fabric | 450 |
| SLING_FL | FTIP_L | SEAT_L | fabric | 208 |
| SLING_RL | SEAT_L | RTIP_L | fabric | 321 |
| LEG_FR | HUB_R | DOCK_FR | tube | 376 |
| LEG_RR | HUB_R | DOCK_RR | tube | 376 |
| POLE_R | HUB_R | RTIP_R | tube | 491 |
| POST_R | HUB_R | FTIP_R | tube | 162 |
| SIDE_CORD_R | DOCK_FR | DOCK_RR | cord | 660 |
| FORESTAY_R | FTIP_R | DOCK_FR | cord | 416 |
| AFTSTAY_R | FTIP_R | DOCK_RR | cord | 502 |
| BACKSTAY_R | RTIP_R | DOCK_RL | cord | 714 |
| SIDE_STRAP_R | FTIP_R | RTIP_R | fabric | 450 |
| SLING_FR | FTIP_R | SEAT_R | fabric | 208 |
| SLING_RR | SEAT_R | RTIP_R | fabric | 321 |

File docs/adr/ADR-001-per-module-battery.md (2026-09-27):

# ADR-001 — The wheel module is the battery

Status: accepted · 2026-09

**Context.** The sketch shows one box with battery, motor, gearbox, brake and electronics, "4× redundant unit". A central pack would be lighter per Wh and simpler to charge, but it puts traction current through the docks and makes the module depend on the frame.

**Decision.** Each wheel module carries its own 7s1p pack (85.7 Wh). The vehicle power bus runs at pack voltage; modules feed it through ideal diodes and take charge through a current limit. Traction current never crosses a dock.

**Consequences.** Docks carry ≤ 5 A and can be cheap M12 connectors. A module is a complete, testable, chargeable unit — the fleet rack is just docks. Packs stay under 100 Wh, which simplifies transport. Cost: four BMSs instead of one, ~0.4 kg of extra enclosure, and per-pack imbalance managed by the charge limiter.

**Rejected.** Central pack in the B node (traction over docks, single point of failure); swappable central pack (heavier dock, no per-module test).

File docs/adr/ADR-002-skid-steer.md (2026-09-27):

# ADR-002 — Skid steer, no steering mechanism

Status: accepted · 2026-09

**Context.** Four identical modules cannot include steering geometry without becoming non-identical (a steered front module differs from a rear one).

**Decision.** Differential (skid) steering: left tread drives both left wheels, right tread both right wheels. Modules only need to know their side, which the dock tells them.

**Consequences.** Zero-radius turns; scrub on hard playa is harmless at 8 km/h; the turn-rate limiter `|ω|·|v| ≤ 0.25 g` is required in firmware because the geometry allows very fast yaw. Rider training: two treads, like a tracked vehicle.

**Rejected.** Ackermann steering (two module types, a steering column); castor front wheels (non-driven modules, poor sand performance).

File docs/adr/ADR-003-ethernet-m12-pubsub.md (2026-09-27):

# ADR-003 — Ethernet-only signalling, UDP multicast, geographic addressing

Status: accepted · 2026-09

**Context.** The brief: only Ethernet (or better) jacks and cables for signals; every device joins a pub/sub pool on a router; power on its own system.

**Decision.** 100BASE-TX over M12 D-coded connectors through an unmanaged switch in the B node; UDP multicast JSON messages, no broker; a separate M12 A-coded power/ID connector whose ID pin tells a node which dock it is in.

**Consequences.** Any laptop can sniff or inject on the bus for diagnostics; nodes are configuration-free; the switch is a single point of failure that fails safe (no messages = stop). 10BASE-T1S single-pair Ethernet is reserved as v2 ("do better").

**Rejected.** CAN (not Ethernet; needs addressing config); PoE (unnecessary with a 25 V bus, heavier ports); a broker (MQTT) — a master that can die.

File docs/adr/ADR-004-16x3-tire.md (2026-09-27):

# ADR-004 — 16 × 3.0 folding tubeless tire, packed deflated

Status: accepted · 2026-09

**Context.** Flotation on sand wants a big soft tire; the 62-inch bag wants a small one; the 50 lb limit wants a light one.

**Decision.** 16 × 3.0 (ISO 76-305) folding-bead tubeless. ~40 kPa ground pressure at PS-125, fits the 430 mm bag section only when deflated (Ø400).

**Consequences.** Excellent on playa, workable on dry sand at crawl speed. Packing needs a pump and tubeless reseating on site (T-11). Variants: PS-Lite 16 × 2.4 (lighter, worse sand), PS-Sand 20 × 4.0 (30 kPa, two-bag pack).

**Rejected.** 20 × 4.0 as baseline (breaks the one-bag rule); 12-inch solid tires (no flotation).

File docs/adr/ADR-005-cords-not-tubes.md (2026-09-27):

# ADR-005 — Dyneema cords close the truss; the seat is structural

Status: accepted · 2026-09

**Context.** A rigid chair frame needs many tubes and heavy joints. A camp chair gets its stiffness from the fabric.

**Decision.** Tubes only where compression is needed (rails, legs, poles, posts); Dyneema SK78 5 mm cords for every tension diagonal; the seat's side straps and edges are load-bearing members with their own rating and proof test.

**Consequences.** 0.74 kg of tube for the whole frame; the backrest is a mechanism without the seat (which is how it packs); cord and seat-edge safety factors (3.0–3.7) govern the rating rather than the tubes (≥ 9).

**Rejected.** All-tube space frame (+1.5 kg, more joiners); wire rope (heavier, kinks).

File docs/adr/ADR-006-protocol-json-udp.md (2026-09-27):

# ADR-006 — JSON over UDP multicast for v1, CBOR/zenoh reserved

Status: accepted · 2026-09

**Context.** Messages are tiny (a tread command is ~60 bytes at 50 Hz); readability and tooling matter more than bandwidth on a 100 Mb link with seven nodes.

**Decision.** One JSON object per datagram on 239.77.83.1:7783; schema in `firmware/schemas/`. Heartbeat is implicit in the command stream; presence is the status stream; one node per dock.

**Consequences.** Anyone can debug with `tcpdump` and `jq`. Parsing cost on an MCU is acceptable at these rates. CBOR (same schema, binary) and zenoh-pico are the upgrade path if v2 moves to 10BASE-T1S.

**Rejected.** Protobuf (tooling weight); custom binary (unreadable on the playa at 3 a.m.).

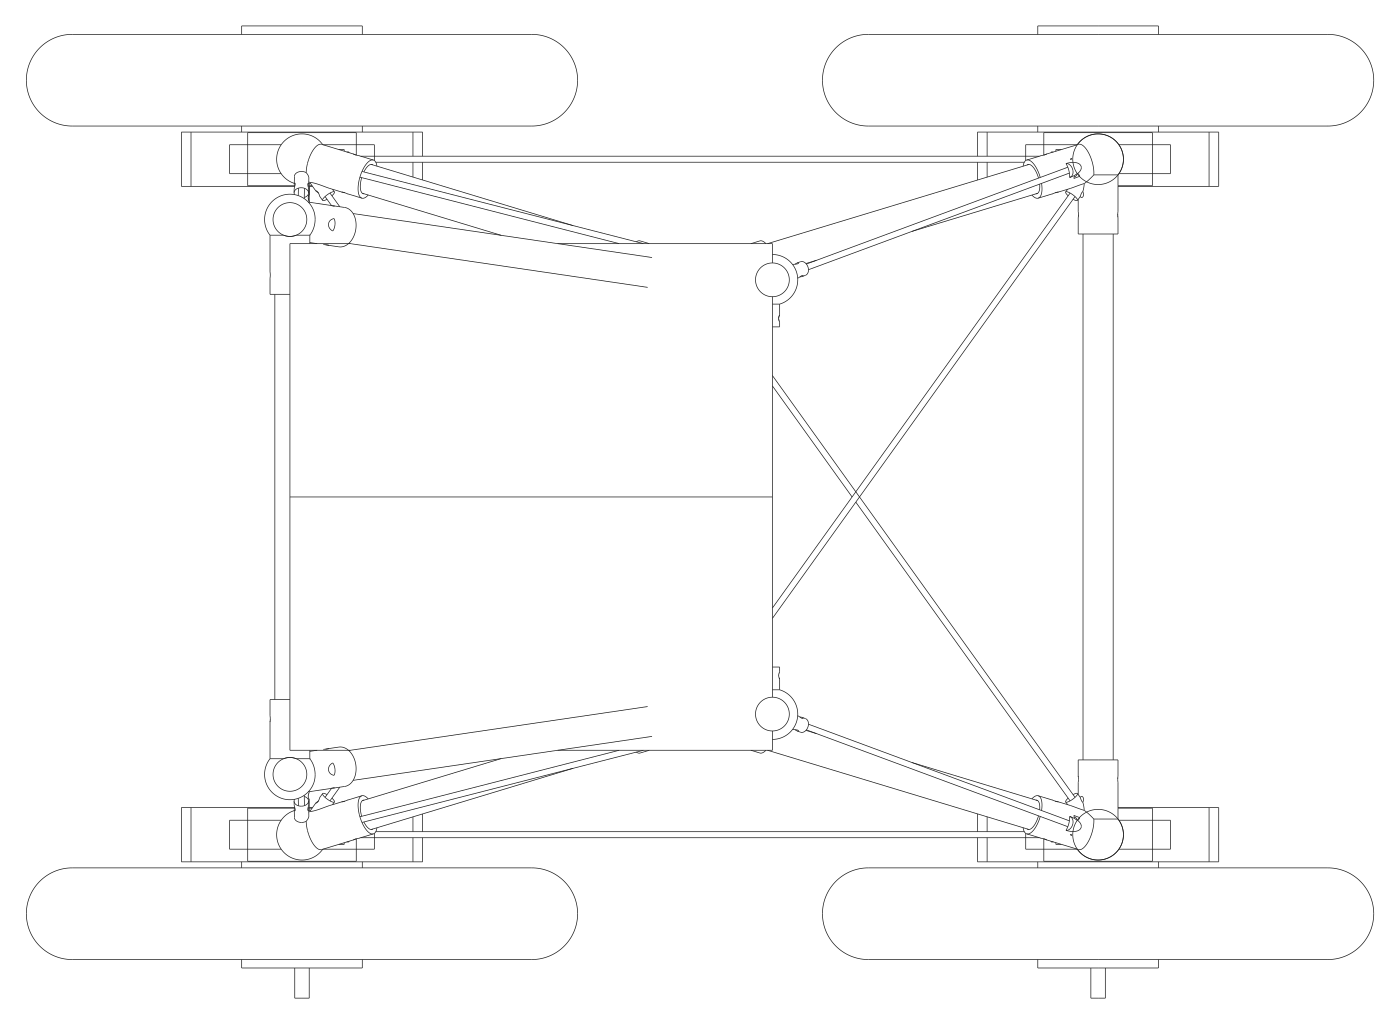
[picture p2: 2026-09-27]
site/assets/view_top.png

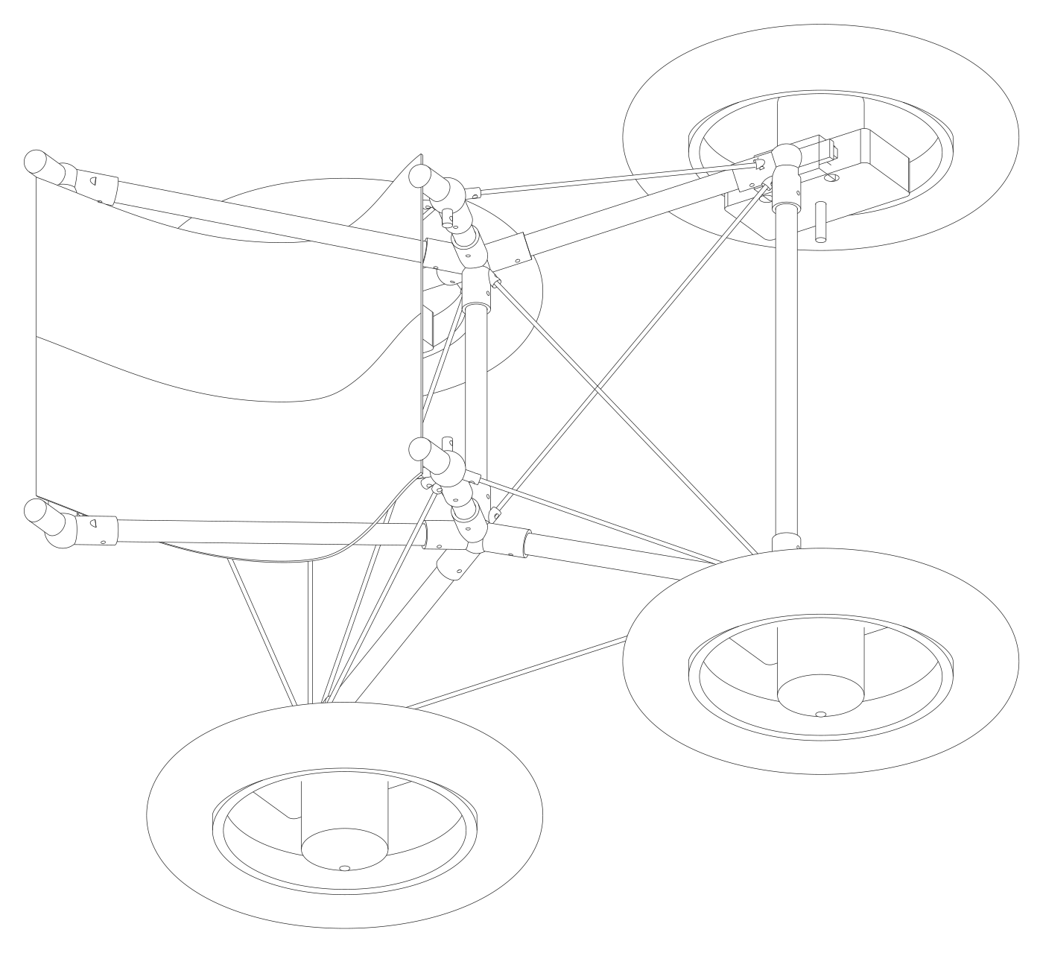
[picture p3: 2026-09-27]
site/assets/view_iso.png

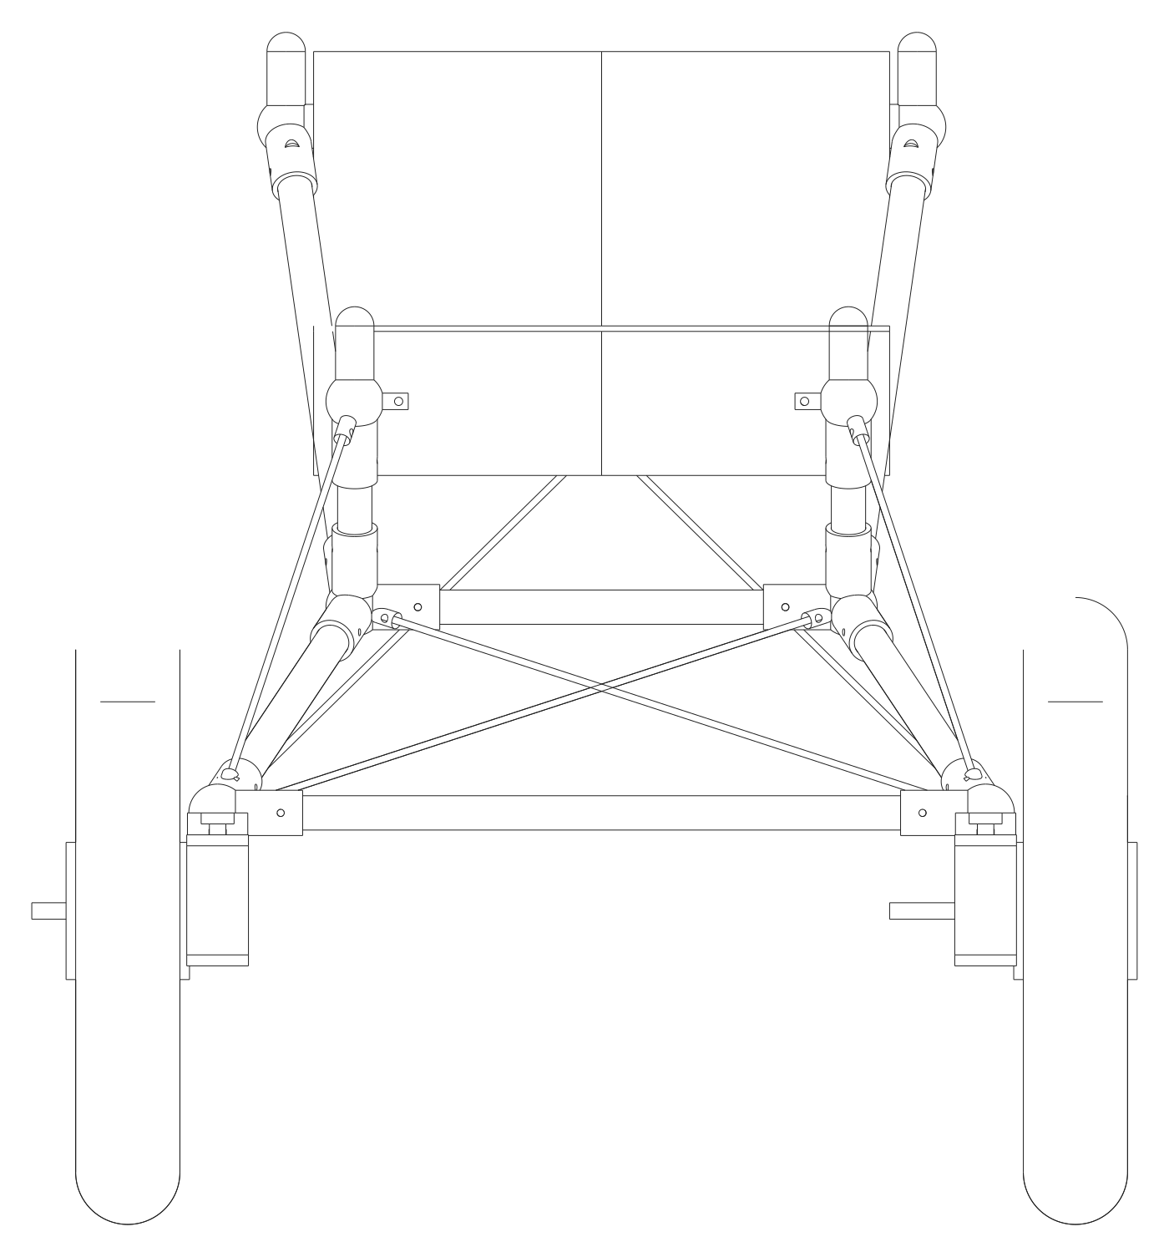
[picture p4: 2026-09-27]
site/assets/view_front.png

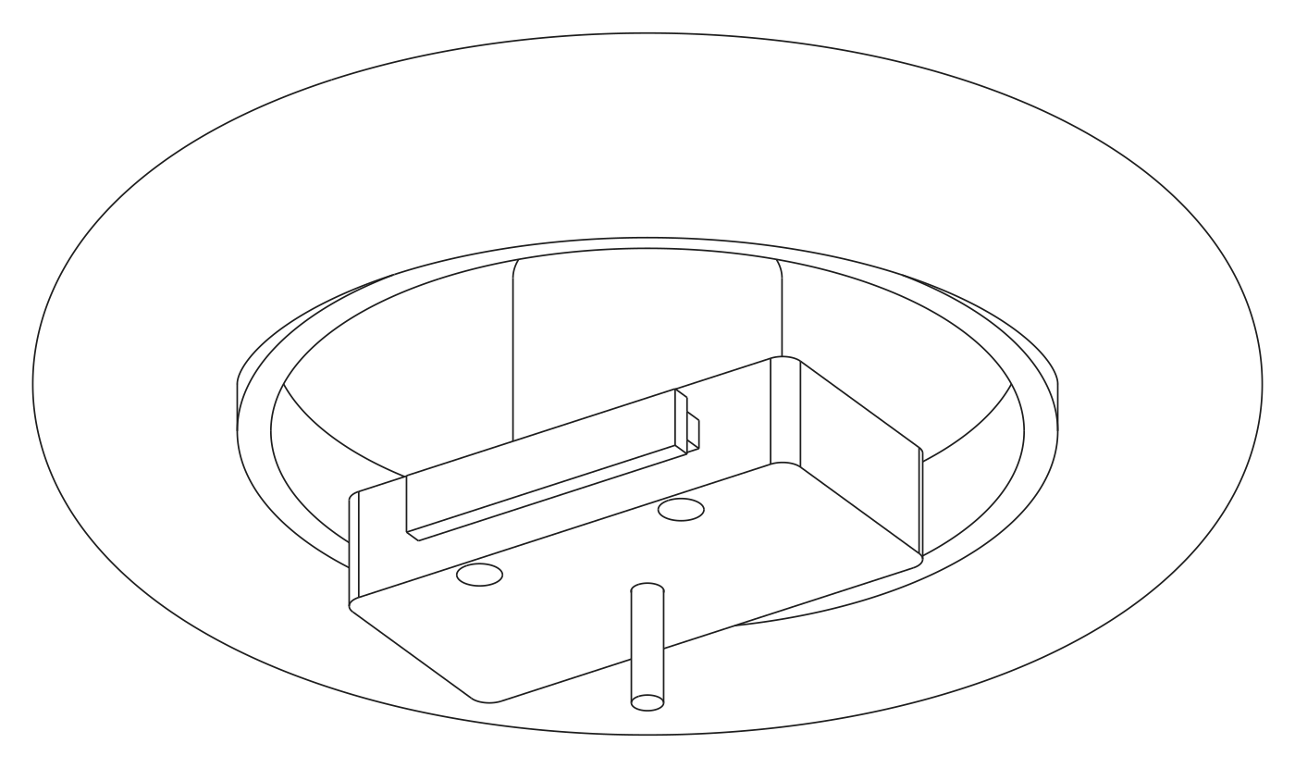
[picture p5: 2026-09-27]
site/assets/view_wheel_module.png

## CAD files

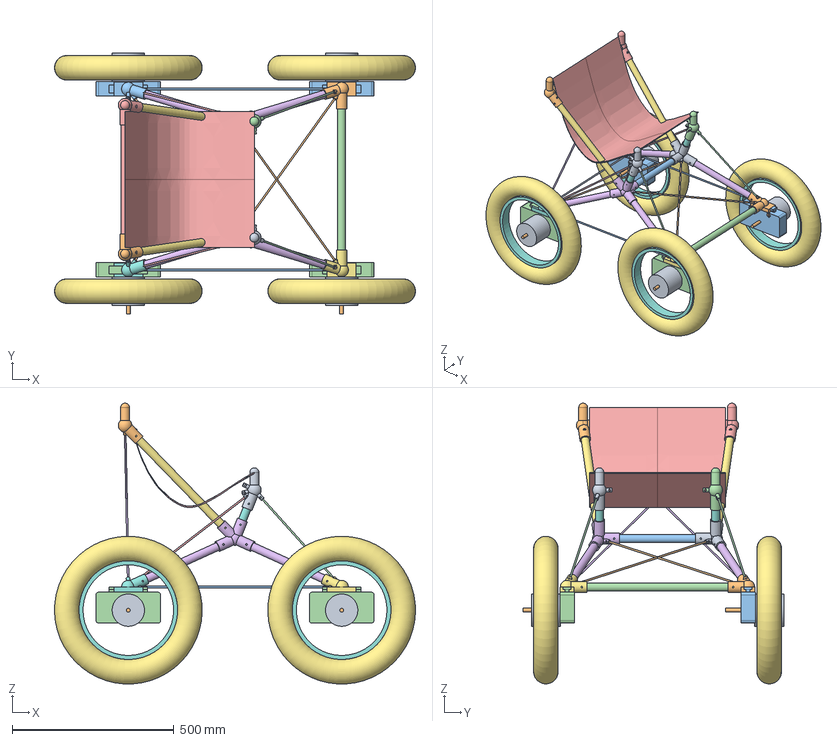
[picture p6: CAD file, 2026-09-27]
cad/exports/playa_sprawler_assembly.step
1116.8 x 806.0 x 868.6 mm

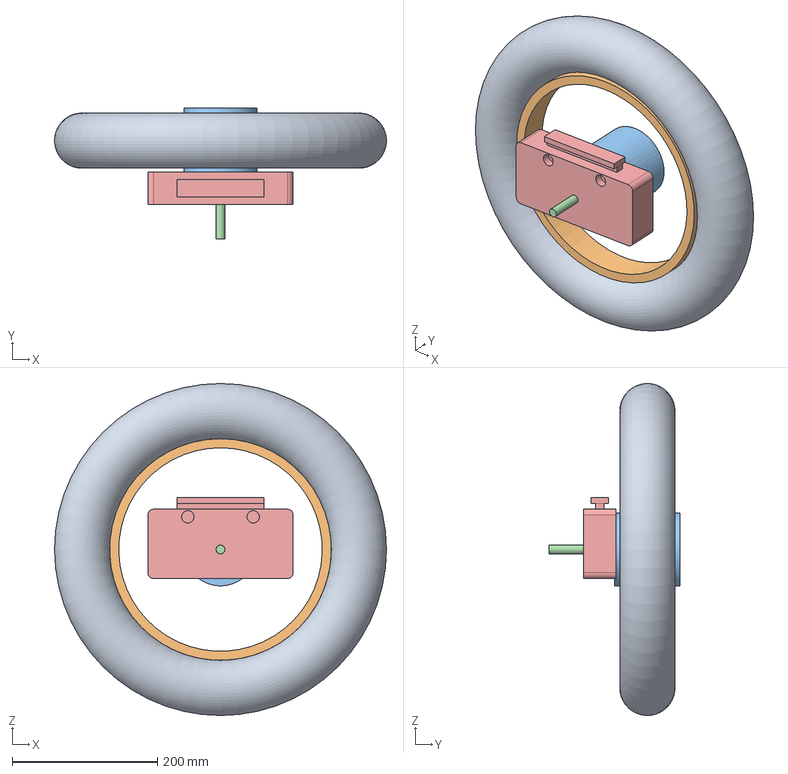
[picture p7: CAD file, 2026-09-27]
cad/exports/wheel_module_assembly.step
457.0 x 180.5 x 457.0 mm

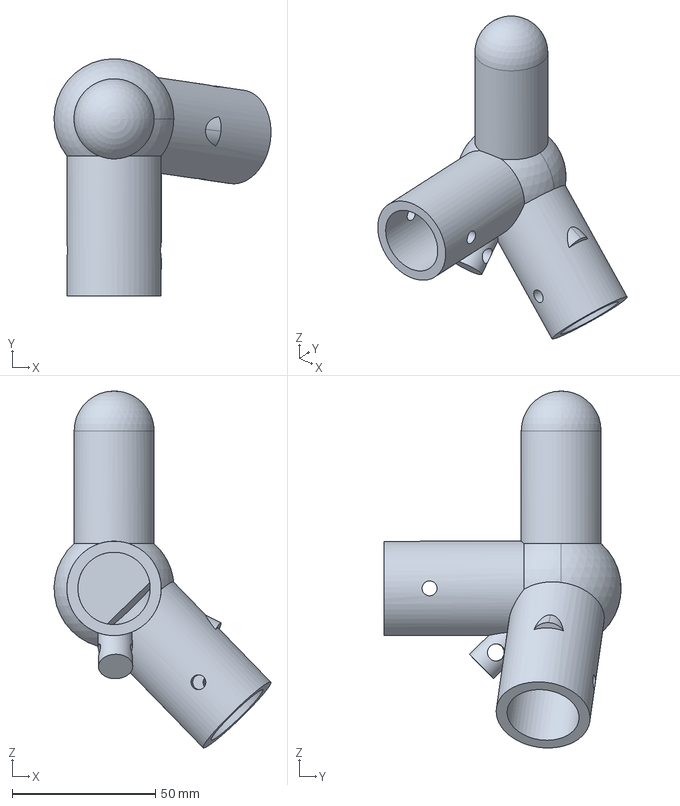
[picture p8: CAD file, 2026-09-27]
cad/exports/joiner_RTIP_L.step
75.9 x 83.0 x 124.8 mm

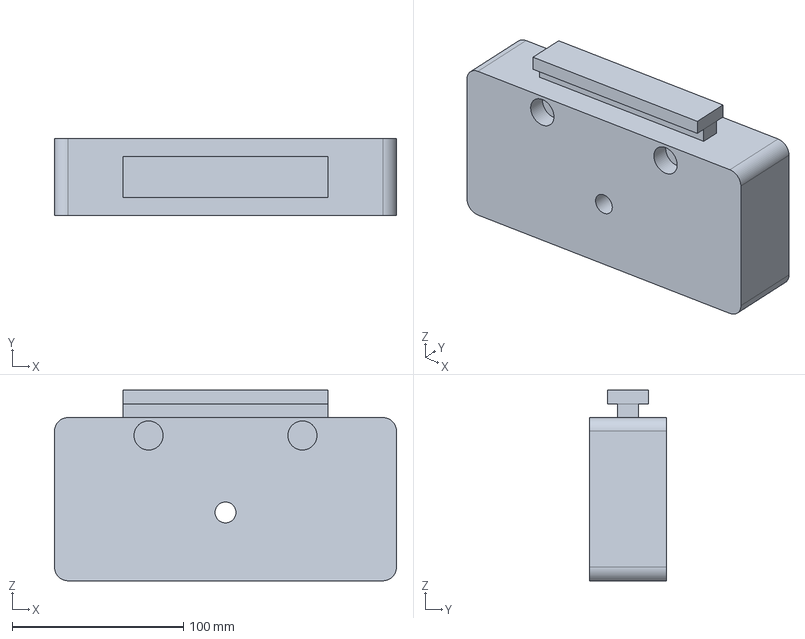
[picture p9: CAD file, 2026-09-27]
cad/exports/wheel_module_carrier.step
200.0 x 45.0 x 111.5 mm

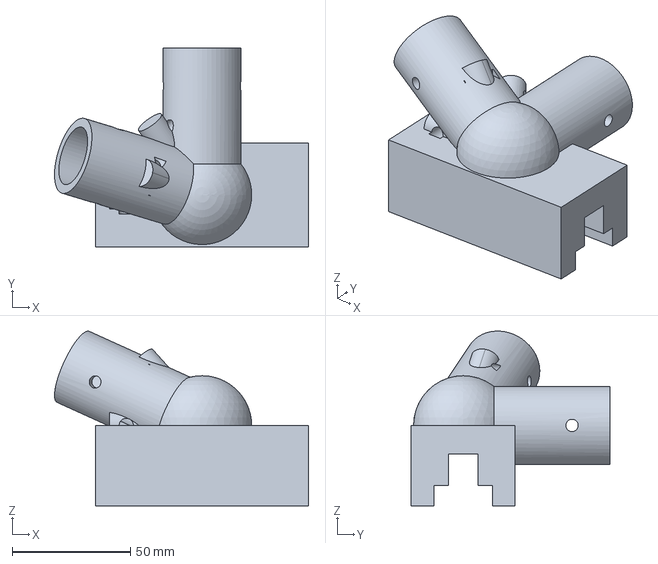
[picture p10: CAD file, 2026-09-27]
cad/exports/joiner_DOCK_FR.step
107.3 x 84.0 x 73.8 mm

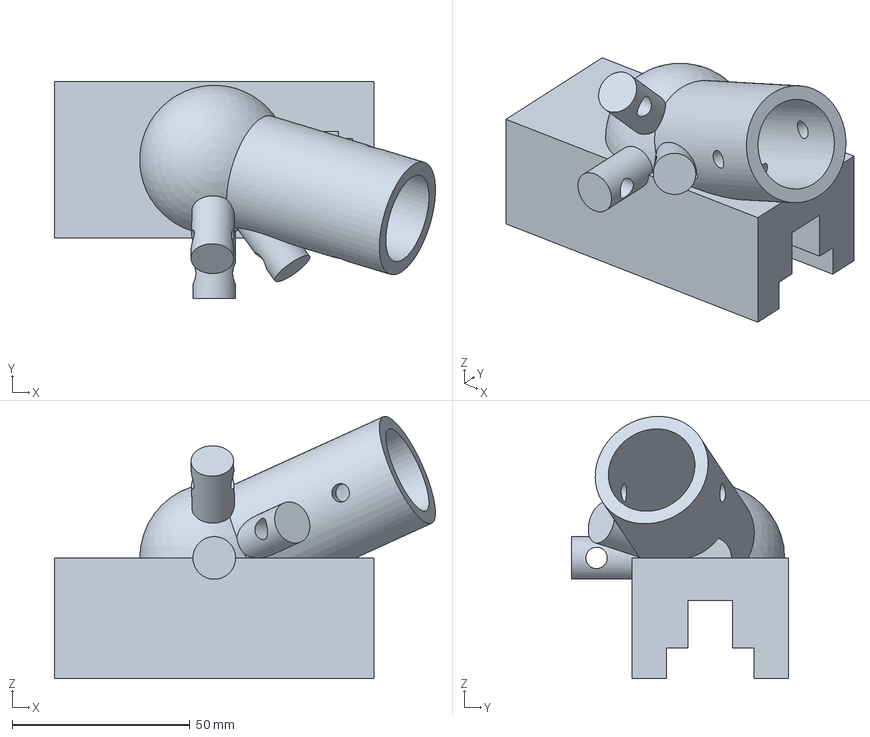
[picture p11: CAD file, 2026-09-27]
cad/exports/joiner_DOCK_RL.step
107.3 x 61.0 x 73.9 mm

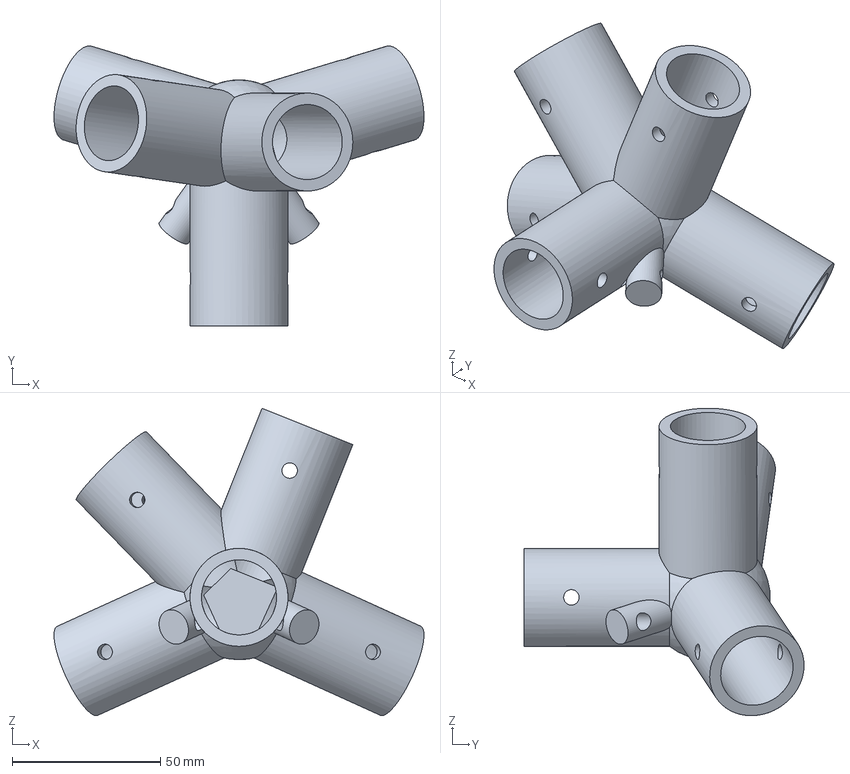
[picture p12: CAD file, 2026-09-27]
cad/exports/joiner_HUB_L.step
124.6 x 94.4 x 103.5 mm

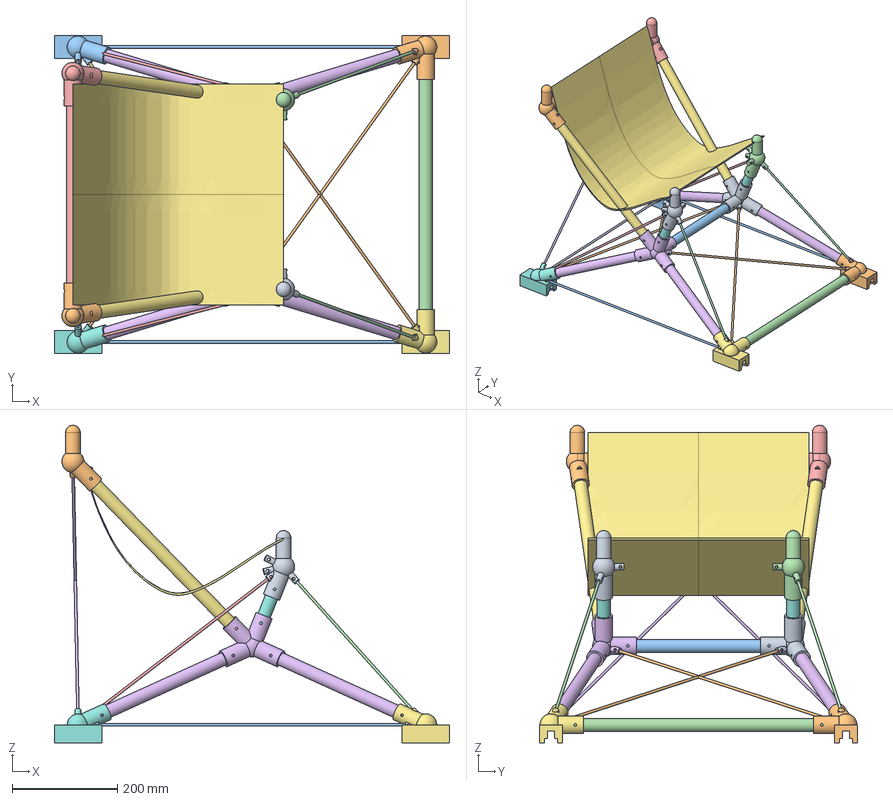
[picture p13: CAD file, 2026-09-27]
cad/exports/frame_and_seat.step
750.0 x 604.0 x 603.0 mm

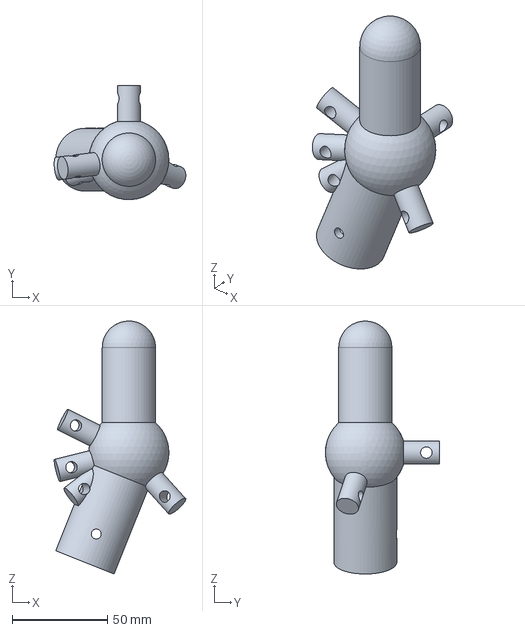
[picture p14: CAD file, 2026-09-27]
cad/exports/joiner_FTIP_R.step
69.1 x 60.0 x 132.7 mm

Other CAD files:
cad/exports/joiner_DOCK_FL.step
cad/exports/joiner_HUB_R.step
cad/exports/joiner_DOCK_RR.step
cad/exports/joiner_FTIP_L.step
cad/exports/joiner_RTIP_R.step
cad/exports/joiner_DOCK_FL.stl
cad/exports/joiner_DOCK_FR.stl
cad/exports/joiner_DOCK_RL.stl
cad/exports/joiner_DOCK_RR.stl
cad/exports/joiner_FTIP_L.stl
cad/exports/joiner_FTIP_R.stl
cad/exports/joiner_HUB_L.stl
cad/exports/joiner_HUB_R.stl
cad/exports/joiner_RTIP_L.stl
cad/exports/joiner_RTIP_R.stl
cad/exports/wheel_module_carrier.stl

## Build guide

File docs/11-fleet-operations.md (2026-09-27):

# 11 — Fleet operations

The reason for all the standardisation: a camp keeps a rack of modules, not a row of vehicles.

## Inventory model

| Pool | Unit | Typical camp of 8 vehicles |
|---|---|---|
| Wheel modules | identical | 32 on vehicles + 8 charging/spare |
| Control modules | identical interface, various inputs | 16 + 4 |
| Bus nodes | identical | 8 + 2 |
| Frames | class-marked kits | 8 + spare tubes/joiners/cords |
| Seats | personal, never pooled | one per rider |

## Charging rack

A row of docks (same rail, same connectors) on a bus bar fed by the camp's power. Modules charge
at ≤ 3 A each; a 32-module night uses ~2.7 kWh. Rack publishes each slot's SoC on the camp LAN.

## Swap procedure (any module, rider seated)

1. Rider releases controls → `stop`.
2. Pull the dock pin, slide the module aft off the rail (front dock) or forward (rear dock).
3. Slide the spare in, pin clicks. Node reads the dock, hellos with its rating.
4. Supervisor: `run` if the rating meets the rider class, otherwise `crawl` — the rider sees it on the control LED.
5. Log auto-records serial in / serial out.

Target ≤ 60 s. The simulator shows the timing.

## Lifecycle states

`new → proof-tested → in service → flagged (fault/status) → inspected → in service | retired`.
A flagged module never goes back on a vehicle without an inspection entry.

## Sign-out

Rider mass + gear → rider class. Steward assigns a vehicle whose rating ≥ rider class; the B node
is set to the rider class so firmware enforces it for the rest of the day.

## Records

The supervisor logs every `hello` (serial, dock, rating) with a timestamp; the fleet steward pulls
logs at charge time. Combined with QR labels this answers "which parts were on the vehicle that
had the incident" in one query.

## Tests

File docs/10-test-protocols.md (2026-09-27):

# 10 — Test protocols

Each test records: part IDs, class, date, tester, instrument, result, pass/fail. Results go in the
rating record; failures go in an issue with the part quarantined.

| ID | Test | Method | Pass |
|---|---|---|---|
| T-1 | Tube 3-point bend | 25 × 22 CF sample, 300 mm span, load to failure ×3 per batch | ultimate ≥ 450 MPa flexural; stiffness within 15 % of E = 80 GPa |
| T-2 | Socket pull-out and bearing | joiner socket + bonded tube stub, axial pull and 90° prying | ≥ 2 × LC2 member force for the class, no crack |
| T-3 | Latch / dock pull-out | module on dock, pull along rail and vertical lift, 1.5 × LC2 wheel load | pin holds; shoe strain recovers |
| T-4 | Cord and seat-edge tensile | 5 mm cord with spliced eye ×3; seat edge webbing sample ×3 | cord ≥ 9 kN with eyes (0.5 knocked), edge ≥ 6 kN |
| T-5 | Static proof | assembled frame + seat, 1.5 × class payload on the seat for 60 s; each joiner also individually | no damage, permanent set ≤ 0.5 mm, deflection within 10 % of prediction |
| T-6 | Drop | class payload dummy, 150 mm drop onto hard playa-equivalent, ×10 | no damage; wheel status shows no fault |
| T-7 | Dyno and range | module on roller, 8 km/h at loads for each CRR row; full-vehicle loop on hard playa | drive efficiency ≥ 0.70; range ≥ 15 km |
| T-8 | Brake and hold | 8 km/h stop on level and 10 % downgrade; hold on 10 % for 5 min | stop ≤ 1.5 m; no roll-back |
| T-9 | Comms fail-safe | pull each cable in turn while rolling; kill the B node; flood the bus with malformed packets | affected wheels stop ≤ 0.5 s; vehicle never accelerates |
| T-10 | Hot-swap timing | rider seated; swap each module in turn; swap a control module; swap in a lower-rated module | ≤ 60 s each; `crawl` on the low part; `run` after replacement |
| T-11 | Pack / unpack | one person, no tools, from bag to rolling and back, ×3 | ≤ 15 min each way; bag ≤ 50 lb on a checked scale |
| T-12 | Dust and water | IP5X dust chamber on a module; IPX4 spray | no ingress at connectors or battery bay |
| T-13 | Thermal | soft-playa 10 % grade equivalent for 20 min at 40 °C ambient | motor < 95 °C, controller < 85 °C |
| T-14 | Stability | tilt table with class dummy | lift-off ≥ 24° side slope (0.45 g) |

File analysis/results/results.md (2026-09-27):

# Playa Sprawler — analysis results (v0.1.0, generated 2026-09-08)

Everything below is computed by `analysis/run_all.py` from `analysis/ps_params.py`. Re-run after any parameter change. Idealisations are stated in each script's docstring.

### One-bag pack (660 × 450 × 450 mm duffel = 61.4 linear inches, limit 62)

- Four wheel modules stacked axially: 540 mm of the 640 mm bag length; 100 mm slab remains for tubes, seat, controls and bus node.
- Wheel OD 457 mm inflated: fits the 430 × 430 mm section? **no** → pack with tires deflated (400 mm): **yes**.
- Longest tube segment 376 mm (shock-corded splits below): fits crosswise? **yes**.
- Corner voids beside the wheel stack: ~32 L for control modules, bus node, harness, cords.
- Mass: **22.49 kg of 22.68 kg** (50 lb) → margin +0.19 kg (+0.8%).

| Mass budget item | Target (kg) |
|---|---|
| Wheel module (x4) | 17.40 |
| Frame tubes (carbon) | 0.74 |
| Joiners (printed) + hardware | 0.90 |
| Cords + tensioners | 0.15 |
| Seat canvas | 0.70 |
| Control modules (x2) | 0.60 |
| Bus node (switch + supervisor + power) | 0.55 |
| Harness (M12 data + power) | 0.65 |
| Bag | 0.80 |
| **Total** | **22.49** |

| Wheel module breakdown | kg |
|---|---|
| hub motor | 1.90 |
| rim + spokes | 0.62 |
| tire (tubeless) + sealant | 0.80 |
| battery pack | 0.41 |
| controller + node board | 0.15 |
| carrier (printed + Al torque plates) | 0.35 |
| connectors + fasteners | 0.10 |
| **Module total** | **4.33** |

| Tube member | Length (mm) | Segments | Segment length (mm) |
|---|---|---|---|
| SEAT_RAIL | 360 | 1 | 360 |
| CTRL_RAIL | 560 | 2 | 280 |
| TOP_RAIL | 460 | 2 | 230 |
| LEG_FL | 376 | 1 | 376 |
| LEG_RL | 376 | 1 | 376 |
| POLE_L | 491 | 2 | 245 |
| POST_L | 162 | 1 | 162 |
| LEG_FR | 376 | 1 | 376 |
| LEG_RR | 376 | 1 | 376 |
| POLE_R | 491 | 2 | 245 |
| POST_R | 162 | 1 | 162 |

---

## Rating class PS-100 (payload 100 kg)

### Frame truss — payload 100 kg

| Case | Kind | Max displacement (mm) | Worst tube SF (buckling) | Worst tube SF (strength) | Worst cord SF | Worst seat-edge SF | Slack tension members | Mechanism? |
|---|---|---|---|---|---|---|---|---|
| LC1 Static seated | deflection | 12.4 (RTIP_R) | 34.7 | 40.3 | 11.7 | 11.4 | XF_1, BACKSTAY_L, AFTSTAY_R | no |
| LC2 Dynamic vertical (bump/drop) | ultimate | 31.0 (RTIP_R) | 13.9 | 16.1 | 4.7 | 4.6 | XF_1, BACKSTAY_L, AFTSTAY_R | no |
| LC3 Lateral skid / turn | ultimate | 42.4 (RTIP_L) | 15.7 | 18.3 | 6.0 | 7.1 | XF_1, XR_1, XR_2, AFTSTAY_L, BACKSTAY_R | no |
| LC5 Backrest lean | ultimate | 26.6 (RTIP_R) | 22.9 | 26.6 | 8.2 | 8.7 | XF_2, AFTSTAY_R, BACKSTAY_R | no |

#### LC2 member forces (ultimate case, 2.5 g)

| Member | Type | Length (mm) | Axial (N, + tension) | SF buckling | SF strength/cord |
|---|---|---|---|---|---|
| SEAT_RAIL | tube | 360 | -1614 | 29.0 | 30.9 |
| CTRL_RAIL | tube | 560 | +529 | inf | 94.2 |
| TOP_RAIL | tube | 460 | +26 | inf | 1950.7 |
| SEAT_CROSS | fabric | 410 | +0 | nan | 17322670070.7 |
| SEAT_FRONT_EDGE | fabric | 360 | +438 | nan | 13.7 |
| REAR_CORD | cord | 560 | +557 | — | 16.2 |
| XF_1 | cord | 586 | +0 | — | inf |
| XF_2 | cord | 586 | +0 | — | 198986624.5 |
| XR_1 | cord | 586 | +41 | — | 220.0 |
| XR_2 | cord | 586 | +41 | — | 220.0 |
| LEG_FL | tube | 376 | -3092 | 13.9 | 16.1 |
| LEG_RL | tube | 376 | -2215 | 19.3 | 22.5 |
| POLE_L | tube | 491 | -1671 | 15.1 | 29.8 |
| POST_L | tube | 162 | -985 | 235.8 | 50.6 |
| SIDE_CORD_L | cord | 660 | +1921 | — | 4.7 |
| FORESTAY_L | cord | 416 | +1220 | — | 7.4 |
| AFTSTAY_L | cord | 502 | -0 | — | inf |
| BACKSTAY_L | cord | 714 | +0 | — | inf |
| SIDE_STRAP_L | fabric | 450 | +383 | nan | 15.7 |
| SLING_FL | fabric | 208 | +849 | nan | 7.1 |
| SLING_RL | fabric | 321 | +1313 | nan | 4.6 |
| LEG_FR | tube | 376 | -3092 | 13.9 | 16.1 |
| LEG_RR | tube | 376 | -2215 | 19.3 | 22.5 |
| POLE_R | tube | 491 | -1671 | 15.1 | 29.8 |
| POST_R | tube | 162 | -985 | 235.8 | 50.6 |
| SIDE_CORD_R | cord | 660 | +1921 | — | 4.7 |
| FORESTAY_R | cord | 416 | +1220 | — | 7.4 |
| AFTSTAY_R | cord | 502 | +0 | — | inf |
| BACKSTAY_R | cord | 714 | -0 | — | inf |
| SIDE_STRAP_R | fabric | 450 | +383 | nan | 15.7 |
| SLING_FR | fabric | 208 | +849 | nan | 7.1 |
| SLING_RR | fabric | 321 | +1313 | nan | 4.6 |

Front seat post, bounding case with the forestay slack (pure cantilever, LC2): moment 29.6 N·m, tube stress 48 MPa (SF 9.3), socket bearing 1.6 MPa (SF 25.3 on knocked-down printed strength).

### Stability and turn-rate limiter

Combined CG height 694 mm; track 691 mm; wheelbase 660 mm.
Quasi-static tipping threshold: 0.50 g lateral (26° side slope), 0.48 g longitudinal.
Firmware limiter target: 0.25 g lateral (margin 2.0x on the geometric threshold); rule `|omega| * |v| <= a_lat_max, omega = (vR - vL) / track`.
At the 8 km/h cap the tightest permitted radius is 2.0 m; stopping distance at 0.30 g is 0.8 m.

| Turn radius (m) | Speed allowed (km/h) |
|---|---|
| 0.5 | 4.0 |
| 1.0 | 5.6 |
| 1.5 | 6.9 |
| 2.0 | 8.0 |
| 3.0 | 8.0 |
| 5.0 | 8.0 |

### Traction, torque and range (gross mass 122 kg, usable energy 291 Wh, 8 km/h)

| Surface | Grade | Drawbar force (N) | Electrical power (W) | Per-wheel motor load (W) | Per-wheel torque (N·m) | Range (km) | Within motor rating? |
|---|---|---|---|---|---|---|---|
| playa, hard | 0% | 24 | 86 | 19 | 1.4 | 27.2 | yes |
| playa, hard | 10% | 143 | 465 | 114 | 8.2 | 5.0 | yes |
| playa, soft/dusty | 0% | 72 | 237 | 57 | 4.1 | 9.8 | yes |
| playa, soft/dusty | 10% | 191 | 616 | 152 | 10.9 | 3.8 | yes |
| beach, wet firm | 0% | 60 | 199 | 47 | 3.4 | 11.7 | yes |
| beach, wet firm | 10% | 179 | 578 | 142 | 10.2 | 4.0 | yes |
| beach, dry loose | 0% | 239 | 768 | 189 | 13.6 | 3.0 | yes |
| beach, dry loose | 10% | 358 | 1147 | 284 | 20.5 | 2.0 | torque limit — derate speed |

Motor basis: mini geared hub motor, no-clutch (regen-capable) variant preferred, 250 W nominal / 500 W peak, 20 N·m rated / 35 N·m peak. Drive efficiency 0.70 assumed at low speed; verify on the dynamometer test.

### Flotation (per-wheel load 298 N, dry-sand target ≤ 40 kPa)

| Tire | Ground pressure (kPa / psi) | Contact area (cm²) | Patch length (mm) | Tire deflection (mm) | Deflection acceptable (≤ 22% of section)? |
|---|---|---|---|---|---|
| 16 x 3.0 (baseline) | 30 / 4.3 | 99 | 187 | 19 | no — rim-out risk |
| 16 x 3.0 (baseline) | 40 / 5.8 | 75 | 140 | 11 | yes |
| 16 x 3.0 (baseline) | 55 / 8.0 | 54 | 102 | 6 | yes |
| 16 x 2.4 (PS-Lite) | 30 / 4.3 | 99 | 233 | 32 | no — rim-out risk |
| 16 x 2.4 (PS-Lite) | 40 / 5.8 | 75 | 175 | 18 | no — rim-out risk |
| 16 x 2.4 (PS-Lite) | 55 / 8.0 | 54 | 127 | 9 | yes |
| 20 x 4.0 (PS-Sand, two-bag pack) | 30 / 4.3 | 99 | 142 | 10 | yes |
| 20 x 4.0 (PS-Sand, two-bag pack) | 40 / 5.8 | 75 | 107 | 6 | yes |
| 20 x 4.0 (PS-Sand, two-bag pack) | 55 / 8.0 | 54 | 78 | 3 | yes |

Model: contact pressure ≈ inflation pressure; patch width ≈ 0.7 × section width; deflection ≈ L²/8R. Beach wheelchairs run 20–30 kPa; the 16 x 3.0 baseline lands at ~40 kPa, which is workable on dry sand at crawl speed and excellent on playa. The 20 x 4.0 variant buys real dry-sand flotation at the cost of the one-bag pack.

### Wheel-module axle, cantilever check (LC2, 2.5 g)

Sprung load per wheel 639 N at 45 mm cantilever → bending 28.8 N·m plus peak motor torque 35 N·m.
Bending stress 226 MPa, shear 138 MPa, von Mises 328 MPa on a 12 mm axle with 10 mm flats.
Safety factor 2.39 against an assumed yield of 785 MPa (target 1.5). **The axle steel grade must be verified per motor model; if it cannot be, the module carrier must support the axle on both sides.**

---

## Rating class PS-125 (payload 125 kg)

### Frame truss — payload 125 kg

| Case | Kind | Max displacement (mm) | Worst tube SF (buckling) | Worst tube SF (strength) | Worst cord SF | Worst seat-edge SF | Slack tension members | Mechanism? |
|---|---|---|---|---|---|---|---|---|
| LC1 Static seated | deflection | 15.5 (RTIP_R) | 27.7 | 32.2 | 9.4 | 9.1 | XF_1, BACKSTAY_L, AFTSTAY_R | no |
| LC2 Dynamic vertical (bump/drop) | ultimate | 38.8 (RTIP_R) | 11.1 | 12.9 | 3.7 | 3.7 | XF_1, BACKSTAY_L, AFTSTAY_R | no |
| LC3 Lateral skid / turn | ultimate | 53.0 (RTIP_L) | 12.6 | 14.6 | 4.8 | 5.7 | XF_1, XR_1, XR_2, AFTSTAY_L, BACKSTAY_R | no |
| LC5 Backrest lean | ultimate | 33.2 (RTIP_R) | 18.3 | 21.3 | 6.6 | 7.0 | XF_2, AFTSTAY_R, BACKSTAY_R | no |

#### LC2 member forces (ultimate case, 2.5 g)

| Member | Type | Length (mm) | Axial (N, + tension) | SF buckling | SF strength/cord |
|---|---|---|---|---|---|
| SEAT_RAIL | tube | 360 | -2017 | 23.2 | 24.7 |
| CTRL_RAIL | tube | 560 | +661 | inf | 75.4 |
| TOP_RAIL | tube | 460 | +32 | inf | 1560.5 |
| SEAT_CROSS | fabric | 410 | +0 | nan | 13858136251.6 |
| SEAT_FRONT_EDGE | fabric | 360 | +548 | nan | 11.0 |
| REAR_CORD | cord | 560 | +696 | — | 12.9 |
| XF_1 | cord | 586 | +0 | — | inf |
| XF_2 | cord | 586 | +0 | — | 159189319.8 |
| XR_1 | cord | 586 | +51 | — | 176.0 |
| XR_2 | cord | 586 | +51 | — | 176.0 |
| LEG_FL | tube | 376 | -3865 | 11.1 | 12.9 |
| LEG_RL | tube | 376 | -2769 | 15.5 | 18.0 |
| POLE_L | tube | 491 | -2088 | 12.1 | 23.9 |
| POST_L | tube | 162 | -1231 | 188.6 | 40.5 |
| SIDE_CORD_L | cord | 660 | +2401 | — | 3.7 |
| FORESTAY_L | cord | 416 | +1525 | — | 5.9 |
| AFTSTAY_L | cord | 502 | -0 | — | inf |
| BACKSTAY_L | cord | 714 | +0 | — | inf |
| SIDE_STRAP_L | fabric | 450 | +479 | nan | 12.5 |
| SLING_FL | fabric | 208 | +1061 | nan | 5.7 |
| SLING_RL | fabric | 321 | +1641 | nan | 3.7 |
| LEG_FR | tube | 376 | -3865 | 11.1 | 12.9 |
| LEG_RR | tube | 376 | -2769 | 15.5 | 18.0 |
| POLE_R | tube | 491 | -2088 | 12.1 | 23.9 |
| POST_R | tube | 162 | -1231 | 188.6 | 40.5 |
| SIDE_CORD_R | cord | 660 | +2401 | — | 3.7 |
| FORESTAY_R | cord | 416 | +1525 | — | 5.9 |
| AFTSTAY_R | cord | 502 | +0 | — | inf |
| BACKSTAY_R | cord | 714 | -0 | — | inf |
| SIDE_STRAP_R | fabric | 450 | +479 | nan | 12.5 |
| SLING_FR | fabric | 208 | +1061 | nan | 5.7 |
| SLING_RR | fabric | 321 | +1641 | nan | 3.7 |

Front seat post, bounding case with the forestay slack (pure cantilever, LC2): moment 37.0 N·m, tube stress 60 MPa (SF 7.5), socket bearing 2.0 MPa (SF 20.3 on knocked-down printed strength).

### Stability and turn-rate limiter

Combined CG height 709 mm; track 691 mm; wheelbase 660 mm.
Quasi-static tipping threshold: 0.49 g lateral (26° side slope), 0.47 g longitudinal.
Firmware limiter target: 0.25 g lateral (margin 1.9x on the geometric threshold); rule `|omega| * |v| <= a_lat_max, omega = (vR - vL) / track`.
At the 8 km/h cap the tightest permitted radius is 2.0 m; stopping distance at 0.30 g is 0.8 m.

| Turn radius (m) | Speed allowed (km/h) |
|---|---|
| 0.5 | 4.0 |
| 1.0 | 5.6 |
| 1.5 | 6.9 |
| 2.0 | 8.0 |
| 3.0 | 8.0 |
| 5.0 | 8.0 |

### Traction, torque and range (gross mass 147 kg, usable energy 291 Wh, 8 km/h)

| Surface | Grade | Drawbar force (N) | Electrical power (W) | Per-wheel motor load (W) | Per-wheel torque (N·m) | Range (km) | Within motor rating? |
|---|---|---|---|---|---|---|---|
| playa, hard | 0% | 29 | 101 | 23 | 1.6 | 23.0 | yes |
| playa, hard | 10% | 173 | 558 | 137 | 9.9 | 4.2 | yes |
| playa, soft/dusty | 0% | 86 | 284 | 69 | 4.9 | 8.2 | yes |
| playa, soft/dusty | 10% | 230 | 741 | 183 | 13.2 | 3.1 | yes |
| beach, wet firm | 0% | 72 | 238 | 57 | 4.1 | 9.8 | yes |
| beach, wet firm | 10% | 216 | 695 | 171 | 12.3 | 3.4 | yes |
| beach, dry loose | 0% | 288 | 924 | 228 | 16.4 | 2.5 | yes |
| beach, dry loose | 10% | 432 | 1381 | 343 | 24.7 | 1.7 | torque limit — derate speed |

Motor basis: mini geared hub motor, no-clutch (regen-capable) variant preferred, 250 W nominal / 500 W peak, 20 N·m rated / 35 N·m peak. Drive efficiency 0.70 assumed at low speed; verify on the dynamometer test.

### Flotation (per-wheel load 360 N, dry-sand target ≤ 40 kPa)

| Tire | Ground pressure (kPa / psi) | Contact area (cm²) | Patch length (mm) | Tire deflection (mm) | Deflection acceptable (≤ 22% of section)? |
|---|---|---|---|---|---|
| 16 x 3.0 (baseline) | 30 / 4.3 | 120 | 225 | 28 | no — rim-out risk |
| 16 x 3.0 (baseline) | 40 / 5.8 | 90 | 169 | 16 | yes |
| 16 x 3.0 (baseline) | 55 / 8.0 | 65 | 123 | 8 | yes |
| 16 x 2.4 (PS-Lite) | 30 / 4.3 | 120 | 281 | 46 | no — rim-out risk |
| 16 x 2.4 (PS-Lite) | 40 / 5.8 | 90 | 211 | 26 | no — rim-out risk |
| 16 x 2.4 (PS-Lite) | 55 / 8.0 | 65 | 153 | 14 | no — rim-out risk |
| 20 x 4.0 (PS-Sand, two-bag pack) | 30 / 4.3 | 120 | 171 | 14 | yes |
| 20 x 4.0 (PS-Sand, two-bag pack) | 40 / 5.8 | 90 | 128 | 8 | yes |
| 20 x 4.0 (PS-Sand, two-bag pack) | 55 / 8.0 | 65 | 93 | 4 | yes |

Model: contact pressure ≈ inflation pressure; patch width ≈ 0.7 × section width; deflection ≈ L²/8R. Beach wheelchairs run 20–30 kPa; the 16 x 3.0 baseline lands at ~40 kPa, which is workable on dry sand at crawl speed and excellent on playa. The 20 x 4.0 variant buys real dry-sand flotation at the cost of the one-bag pack.

### Wheel-module axle, cantilever check (LC2, 2.5 g)

Sprung load per wheel 793 N at 45 mm cantilever → bending 35.7 N·m plus peak motor torque 35 N·m.
Bending stress 280 MPa, shear 138 MPa, von Mises 368 MPa on a 12 mm axle with 10 mm flats.
Safety factor 2.13 against an assumed yield of 785 MPa (target 1.5). **The axle steel grade must be verified per motor model; if it cannot be, the module carrier must support the axle on both sides.**

---

## Rating class PS-150 (payload 150 kg)

### Frame truss — payload 150 kg

| Case | Kind | Max displacement (mm) | Worst tube SF (buckling) | Worst tube SF (strength) | Worst cord SF | Worst seat-edge SF | Slack tension members | Mechanism? |
|---|---|---|---|---|---|---|---|---|
| LC1 Static seated | deflection | 18.6 (RTIP_R) | 23.1 | 26.9 | 7.8 | 7.6 | XF_1, BACKSTAY_L, AFTSTAY_R | no |
| LC2 Dynamic vertical (bump/drop) | ultimate | 46.5 (RTIP_R) | 9.2 | 10.7 | 3.1 | 3.0 | XF_1, BACKSTAY_L, AFTSTAY_R | no |
| LC3 Lateral skid / turn | ultimate | 63.7 (RTIP_L) | 10.5 | 12.2 | 4.0 | 4.7 | XF_1, XR_1, XR_2, AFTSTAY_L, BACKSTAY_R | no |
| LC5 Backrest lean | ultimate | 39.9 (RTIP_R) | 15.2 | 17.7 | 5.5 | 5.8 | XF_2, AFTSTAY_R, BACKSTAY_R | no |

#### LC2 member forces (ultimate case, 2.5 g)

| Member | Type | Length (mm) | Axial (N, + tension) | SF buckling | SF strength/cord |
|---|---|---|---|---|---|
| SEAT_RAIL | tube | 360 | -2421 | 19.3 | 20.6 |
| CTRL_RAIL | tube | 560 | +793 | inf | 62.8 |
| TOP_RAIL | tube | 460 | +38 | inf | 1300.4 |
| SEAT_CROSS | fabric | 410 | +0 | nan | 11548446804.1 |
| SEAT_FRONT_EDGE | fabric | 360 | +657 | nan | 9.1 |
| REAR_CORD | cord | 560 | +836 | — | 10.8 |
| XF_1 | cord | 586 | +0 | — | inf |
| XF_2 | cord | 586 | +0 | — | 132657761.9 |
| XR_1 | cord | 586 | +61 | — | 146.7 |
| XR_2 | cord | 586 | +61 | — | 146.7 |
| LEG_FL | tube | 376 | -4638 | 9.2 | 10.7 |
| LEG_RL | tube | 376 | -3323 | 12.9 | 15.0 |
| POLE_L | tube | 491 | -2506 | 10.1 | 19.9 |
| POST_L | tube | 162 | -1477 | 157.2 | 33.7 |
| SIDE_CORD_L | cord | 660 | +2882 | — | 3.1 |
| FORESTAY_L | cord | 416 | +1830 | — | 4.9 |
| AFTSTAY_L | cord | 502 | -0 | — | inf |
| BACKSTAY_L | cord | 714 | +0 | — | inf |
| SIDE_STRAP_L | fabric | 450 | +575 | nan | 10.4 |
| SLING_FL | fabric | 208 | +1273 | nan | 4.7 |
| SLING_RL | fabric | 321 | +1969 | nan | 3.0 |
| LEG_FR | tube | 376 | -4638 | 9.2 | 10.7 |
| LEG_RR | tube | 376 | -3323 | 12.9 | 15.0 |
| POLE_R | tube | 491 | -2506 | 10.1 | 19.9 |
| POST_R | tube | 162 | -1477 | 157.2 | 33.7 |
| SIDE_CORD_R | cord | 660 | +2882 | — | 3.1 |
| FORESTAY_R | cord | 416 | +1830 | — | 4.9 |
| AFTSTAY_R | cord | 502 | +0 | — | inf |
| BACKSTAY_R | cord | 714 | -0 | — | inf |
| SIDE_STRAP_R | fabric | 450 | +575 | nan | 10.4 |
| SLING_FR | fabric | 208 | +1273 | nan | 4.7 |
| SLING_RR | fabric | 321 | +1969 | nan | 3.0 |

Front seat post, bounding case with the forestay slack (pure cantilever, LC2): moment 44.4 N·m, tube stress 72 MPa (SF 6.2), socket bearing 2.4 MPa (SF 16.9 on knocked-down printed strength).

### Stability and turn-rate limiter

Combined CG height 719 mm; track 691 mm; wheelbase 660 mm.
Quasi-static tipping threshold: 0.48 g lateral (26° side slope), 0.46 g longitudinal.
Firmware limiter target: 0.25 g lateral (margin 1.9x on the geometric threshold); rule `|omega| * |v| <= a_lat_max, omega = (vR - vL) / track`.
At the 8 km/h cap the tightest permitted radius is 2.0 m; stopping distance at 0.30 g is 0.8 m.

| Turn radius (m) | Speed allowed (km/h) |
|---|---|
| 0.5 | 4.0 |
| 1.0 | 5.6 |
| 1.5 | 6.9 |
| 2.0 | 8.0 |
| 3.0 | 8.0 |
| 5.0 | 8.0 |

### Traction, torque and range (gross mass 172 kg, usable energy 291 Wh, 8 km/h)

| Surface | Grade | Drawbar force (N) | Electrical power (W) | Per-wheel motor load (W) | Per-wheel torque (N·m) | Range (km) | Within motor rating? |
|---|---|---|---|---|---|---|---|
| playa, hard | 0% | 34 | 117 | 27 | 1.9 | 19.9 | yes |
| playa, hard | 10% | 202 | 652 | 160 | 11.5 | 3.6 | yes |
| playa, soft/dusty | 0% | 101 | 331 | 80 | 5.8 | 7.0 | yes |
| playa, soft/dusty | 10% | 269 | 866 | 214 | 15.4 | 2.7 | yes |
| beach, wet firm | 0% | 84 | 277 | 67 | 4.8 | 8.4 | yes |
| beach, wet firm | 10% | 253 | 812 | 201 | 14.4 | 2.9 | yes |
| beach, dry loose | 0% | 337 | 1079 | 267 | 19.2 | 2.2 | power limit — derate speed |
| beach, dry loose | 10% | 505 | 1614 | 401 | 28.9 | 1.4 | torque limit — derate speed |

Motor basis: mini geared hub motor, no-clutch (regen-capable) variant preferred, 250 W nominal / 500 W peak, 20 N·m rated / 35 N·m peak. Drive efficiency 0.70 assumed at low speed; verify on the dynamometer test.

### Flotation (per-wheel load 421 N, dry-sand target ≤ 40 kPa)

| Tire | Ground pressure (kPa / psi) | Contact area (cm²) | Patch length (mm) | Tire deflection (mm) | Deflection acceptable (≤ 22% of section)? |
|---|---|---|---|---|---|
| 16 x 3.0 (baseline) | 30 / 4.3 | 140 | 264 | 38 | no — rim-out risk |
| 16 x 3.0 (baseline) | 40 / 5.8 | 105 | 198 | 21 | no — rim-out risk |
| 16 x 3.0 (baseline) | 55 / 8.0 | 77 | 144 | 11 | yes |
| 16 x 2.4 (PS-Lite) | 30 / 4.3 | 140 | 329 | 63 | no — rim-out risk |
| 16 x 2.4 (PS-Lite) | 40 / 5.8 | 105 | 247 | 36 | no — rim-out risk |
| 16 x 2.4 (PS-Lite) | 55 / 8.0 | 77 | 179 | 19 | no — rim-out risk |
| 20 x 4.0 (PS-Sand, two-bag pack) | 30 / 4.3 | 140 | 201 | 20 | yes |
| 20 x 4.0 (PS-Sand, two-bag pack) | 40 / 5.8 | 105 | 150 | 11 | yes |
| 20 x 4.0 (PS-Sand, two-bag pack) | 55 / 8.0 | 77 | 109 | 6 | yes |

Model: contact pressure ≈ inflation pressure; patch width ≈ 0.7 × section width; deflection ≈ L²/8R. Beach wheelchairs run 20–30 kPa; the 16 x 3.0 baseline lands at ~40 kPa, which is workable on dry sand at crawl speed and excellent on playa. The 20 x 4.0 variant buys real dry-sand flotation at the cost of the one-bag pack.

### Wheel-module axle, cantilever check (LC2, 2.5 g)

Sprung load per wheel 946 N at 45 mm cantilever → bending 42.6 N·m plus peak motor torque 35 N·m.
Bending stress 335 MPa, shear 138 MPa, von Mises 411 MPa on a 12 mm axle with 10 mm flats.
Safety factor 1.91 against an assumed yield of 785 MPa (target 1.5). **The axle steel grade must be verified per motor model; if it cannot be, the module carrier must support the axle on both sides.**
